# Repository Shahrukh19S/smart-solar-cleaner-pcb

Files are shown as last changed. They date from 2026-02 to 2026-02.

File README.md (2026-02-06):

# Automatic Solar Panel Cleaner — PCB & Firmware

A smart PCB for an **automatic solar panel cleaning system**, designed in Altium Designer. The board has been **manufactured, assembled, and tested** in the field.

## Overview

The system cleans solar panels using a brush and water pump, with motion provided by four motors (forward/back, horizontal, brush). It uses three ultrasonic (sonar) sensors for positioning, a rain sensor, WiFi (ESP-01) and Blynk for control, a 16×2 LCD, RTC, and an Arduino Mega as the main controller. Power input is 7–12 V DC; two relays drive the water pump and brush motor.

## 📹 Demo

### SMART SOLAR CLEANER PCB PINOUT:

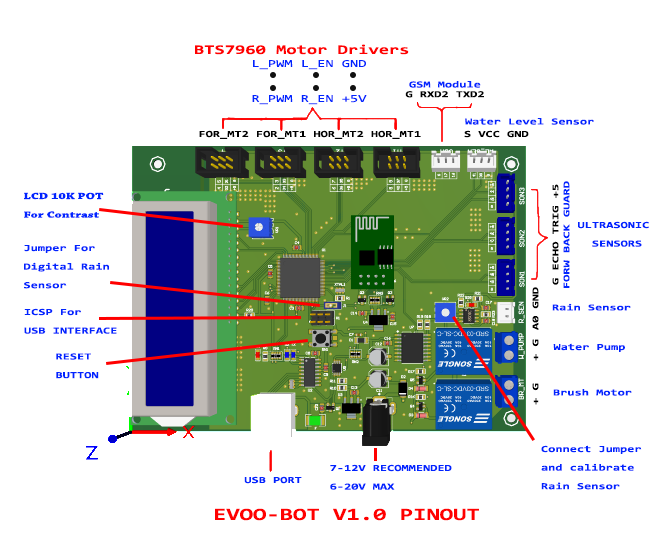
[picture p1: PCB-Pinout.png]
3D View of PCB Board on Altium Designer


## Features

| Category | Details |
|---|---|
| **Controller** | Arduino Mega (ATmega2560) |
| **Connectivity** | ESP-01 (ESP8266) — Blynk app control |
| **Display** | 16×2 LCD |
| **Sensors** | 3× ultrasonic (sonar), rain sensor |
| **Actuators** | 4× motors (2 F/B, 2 horizontal, 1 brush), water pump |
| **Power** | 7–12 V DC input; 2 relays (pump, brush) |
| **Other** | DS3231 RTC, CH340 USB-serial |

## Repository Structure

```
├── README.md                 # This file
├── .gitignore
├── docs/                     # Documentation, schematics, pinout, setup notes
├── hardware/                 # Altium Designer PCB project
│   └── Auto-Solar-Cleaner/   # Source (SchDoc, PcbDoc, PrjPcb) + Gerbers, BOM, DRC
├── firmware/                 # Arduino sketches for this PCB
│   └── Evoo_Bot_V1.0/        # Main firmware (Blynk, RTC, cleaning logic)
├── libraries/                # Arduino/ESP libraries and ESP-01 firmware
└── resources/                # Manuals, reference images
```

## Hardware (PCB)

- **Design tool:** Altium Designer  
- **Location:** `hardware/Auto-Solar-Cleaner/`
- **Source files:** `*.SchDoc`, `*.PcbDoc`, `*.PrjPcb`
- **Manufacturing outputs:** Gerbers, drill files, and assembly data in `Project Outputs for Auto-Solar-Cleaner/`
- **BOM:** `Parts(BOM).xlsx` in the same outputs folder
- **Design rule check:** `Design Rule Check - SOLAR_CLEANER_PCB.html` / `.drc`

Schematic sheets include: ATmega2560, CH340, ESP-01, DS3231, and sensors.

## Firmware

- **Main sketch:** `firmware/Evoo_Bot_V1.0/` — Blynk + RTC + cleaning sequences (dry/wet), sonar-based positioning, rain and water-level checks.
- **Target:** Arduino Mega; serial to ESP-01 for Blynk.
- **Dependencies:** See `firmware/Evoo_Bot_V1.0/README.md` and `libraries/` (Blynk, ESP8266, DS3231, Robojax BTS7960).

Before building, set your Blynk auth token and WiFi credentials. Use `firmware/Evoo_Bot_V1.0/Config.example.h` as a template (copy to `Config.h` and do not commit `Config.h`).

## Libraries

In `libraries/`:

- **Blynk** — `blynk-library-master.zip`, `BlynkESP8266-master.zip`
- **DS3231** — `ds3231FS/` (RTC)
- **Robojax BTS7960** — `Robojax-BTS7960-Motor-driver(Modified)/` (motor driver)
- **ESP-01 AT firmware** — `ESP-At_firmware_1.54/` (Blynk-compatible AT firmware; see `docs/setup-notes.md`)

Install the Arduino libraries and flash the ESP-01 with the provided AT firmware as per the setup notes.

## Documentation

- **Setup and flashing:** `docs/setup-notes.md` (ESP-01 firmware, bootloader, Blynk)
- **Schematics / reference:** `docs/schematics/`, `docs/pinout/`
- **Project overview:** `docs/project-overview.md`

## Bill of Materials (BOM)

- **Location:** `hardware/Auto-Solar-Cleaner/Project Outputs for Auto-Solar-Cleaner/Parts(BOM).xlsx`
- Pick-and-place (centroid) file: `Pick n Place (Centroid).csv` in the same folder.

## Manufacturing & Testing

This PCB has been **manufactured, assembled (hand-soldered), and tested** with the firmware in this repository. Behavior has been verified in real use.

## License

MIT License — see [LICENSE](LICENSE).

## Quick Start

1. Clone the repo and open `hardware/Auto-Solar-Cleaner/Auto-Solar-Cleaner.PrjPcb` in Altium for design review or manufacturing.
2. Install Arduino libraries from `libraries/` and configure Blynk/WiFi (see firmware README and `docs/setup-notes.md`).
3. Flash ESP-01 with `libraries/ESP-At_firmware_1.54/` AT firmware, then build and upload `firmware/Evoo_Bot_V1.0/` to the Arduino Mega.

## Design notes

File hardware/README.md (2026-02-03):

# Hardware — Auto-Solar-Cleaner PCB

Altium Designer project for the **Automatic Solar Panel Cleaner** PCB.

## Contents

- **Source**
  - `Auto-Solar-Cleaner.PrjPcb` — project file (open this in Altium)
  - `*.SchDoc` — schematic sheets (ATmega2560, CH340, ESP-01, DS3231, Sensors)
  - `SOLAR_CLEANER_PCB.PcbDoc` — PCB layout

- **Manufacturing outputs** (`Project Outputs for Auto-Solar-Cleaner/`)
  - **Gerbers** — `.GTL`, `.GBL`, `.GTS`, `.GBS`, `.GTO`, `.GBO`, `.GPT`, `.GPB`, `.GKO`, `.GM*`
  - **Drill** — `.TXT` (round/rect/slot holes), `.LDP`, `.DRR`
  - **Assembly** — `Pick n Place (Centroid).csv`
  - **BOM** — `Parts(BOM).xlsx`
  - **DRC** — `Design Rule Check - SOLAR_CLEANER_PCB.html` / `.drc`
  - **Archive** — `Final PCB (V1).zip`

## Main parts (summary)

- Arduino Mega (ATmega2560), CH340 USB-serial
- ESP-01 (ESP8266), DS3231 RTC
- 16×2 LCD, 3× ultrasonic sensors, rain sensor
- 4× motors (BTS7960 drivers), water pump, brush motor
- 2× relays (pump, brush); 7–12 V DC input

## Viewing without Altium

- Open the **Design Rule Check** report (`.html`) for a net/spec overview.
- View **schematic images** in the repo under `docs/schematics/` (e.g. rain sensor).
- **Pinout:** `docs/pinout/PCB-Pinout.png`

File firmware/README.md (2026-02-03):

# Firmware — Automatic Solar Panel Cleaner

Arduino sketches for the **Auto-Solar-Cleaner** PCB (Arduino Mega + ESP-01, Blynk, RTC, motors, sensors).

## Main sketch: Evoo_Bot_V1.0

- **Path:** `Evoo_Bot_V1.0/`
- **Board:** Arduino Mega (ATmega2560)
- **Features:** Blynk control, RTC scheduling, dry/wet cleaning, 3× sonar positioning, rain and water-level checks, LCD, relay control for pump and brush.

### Dependencies

Install in your Arduino `libraries` folder (or Arduino IDE **Sketch → Include Library → Add .ZIP Library**):

- **Blynk** — from repo `libraries/blynk-library-master.zip` and `libraries/BlynkESP8266-master.zip` (or unzip and copy)
- **ESP8266 for Arduino** — [ESP8266 core](https://github.com/esp8266/Arduino) (for `ESP8266_Lib.h` / Blynk ESP8266)
- **DS3231 RTC** — use repo `libraries/ds3231FS/`
- **Robojax BTS7960** — use repo `libraries/Robojax-BTS7960-Motor-driver(Modified)/`

### Configuration (do not commit secrets)

Set your Blynk auth token and WiFi credentials before compiling:

1. **Option A:** Create a file `Config.h` in the sketch folder (add `#include "Config.h"` in the main `.ino`) with:
   - `char auth[] = "YOUR_BLYNK_AUTH";`
   - `char ssid[] = "YOUR_WIFI_SSID";`
   - `char pass[] = "YOUR_WIFI_PASSWORD";`
2. **Option B:** Edit the placeholders in `Evoo_Bot_V1.0.ino` and **do not commit** those changes (or use a separate private branch).

Add `Config.h` to `.gitignore` (already listed in the repo root `.gitignore`).

### Pin definitions

See `Globals.h`: rain sensor, water level, pump/brush (A1/A2), sonar trigger/echo, motor PWM and enable pins, LCD pins. Matches the PCB design in `hardware/`.

### ESP-01

- Use **Serial1** on the Mega to talk to the ESP-01.
- Flash the ESP-01 with Blynk-compatible AT firmware (e.g. V1.5.4 in `libraries/ESP-At_firmware_1.54/`). See `docs/setup-notes.md`.
- Set ESP-01 baud rate to **9600** (AT command) to match the sketch.

## Other sketches

- **Blynk_RTC** — Blynk + RTC utilities (used or referenced by main logic).
- **SolarCleaner(Original)-Copy** — earlier version of the cleaner logic.
- **NodeMCU** — standalone NodeMCU sketch (optional).

## Building

1. Open `Evoo_Bot_V1.0/Evoo_Bot_V1.0.ino` in the Arduino IDE.
2. Select board **Arduino Mega or Mega 2560** and the correct port.
3. Install all libraries above; add your Blynk/WiFi config.
4. Compile and upload to the Mega.

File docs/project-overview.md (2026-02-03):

# Project Overview — Automatic Solar Panel Cleaner

## System Summary

This project implements a **smart PCB** for an automatic solar panel cleaning robot. The hardware and firmware in this repository have been **manufactured, assembled, and tested** successfully.

## Main Components (from project spec)

1. **Ultrasonic (waterproof) sensors** — 3× (positioning / boundaries)
2. **Rain sensor** — for weather-aware operation
3. **WiFi** — ESP-01 (ESP8266) for Blynk app control
4. **Solar charge controller** — system power management
5. **Automatic battery charging and discharging**
6. **Motors** — 5 in total: 2 forward/back, 2 horizontal, 1 brush
7. **Blynk** — mobile app for scheduling and control
8. **Real-time clock (RTC)** — DS3231 for alarms and scheduling
9. **Target deployment** — e.g. 22 m × 6 m solar panel array; one dedicated panel for the cleaner
10. **SIM module** — (optional) for SMS alerts
11. **Arduino Mega** — main controller
12. **LCD** — 16×2 display
13. **Water level sensor** — tank level for wet cleaning
14. **Water pump** — wet cleaning; controlled via relay

## PCB Highlights

- **Input:** 7–12 V DC  
- **Relays:** 2 — one for water pump, one for brush motor  
- **Design:** Altium Designer (see `hardware/`)

## Documentation Map

- **Setup (ESP-01, bootloader, Blynk):** [setup-notes.md](setup-notes.md)
- **Schematic images:** `docs/schematics/`
- **Pinout:** `docs/pinout/PCB-Pinout.png`
- **Blynk-supported ESP firmwares:** `docs/Blynk_Supported_Firmwares.JPG`

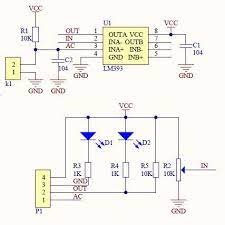
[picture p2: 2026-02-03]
docs/schematics/Rain Sensor Schematic.jpg

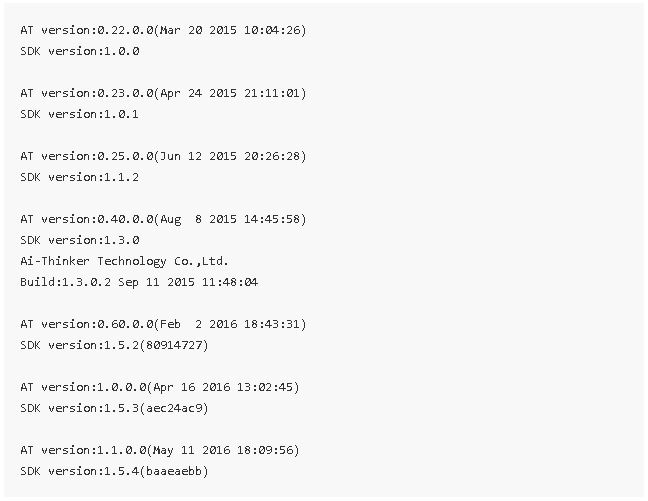
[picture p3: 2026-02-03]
docs/Blynk_Supported_Firmwares.JPG

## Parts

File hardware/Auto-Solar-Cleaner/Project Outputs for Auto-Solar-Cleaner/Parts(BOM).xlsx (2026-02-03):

Designator | Quantity | Mfg Part # | Comment/ value | Footprint | Type | LibRef
XTAL1 | 1 | 16MHz Resonator | 16MHz with 22pF internal capacitors |  | SMD | Crystal Oscillator
TX | 1 | SMT LED | TX LED (Blue) | SMD-0805 | SMD | LED 5V
RX | 1 | SMT LED | RX LED (Blue) | SMD-0805 | SMD | LED 5V
D2 | 1 | 1N4007 | M7 | D0214AC(SMA-2) | SMD | Diode
D1 | 1 | CD1206-SO1575 | Switching Diode by Bourns(Manufacturer) | D1206-RD | SMD | Diode
U7 | 1 | DS3231SN# | Real Time Clock IC | DS3231(footprint) | SMD | DS3231SN#
C11, C12 | 2 | Electrolytic Capacitor | 47uF/ 25V | Elec-Cap-SMD | SMD | Cap Pol2
R_SEN | 1 | JST Connector Male,Pitch 2.54mm, 2-Pin | Rain Sensor Connector | HDR1X2 | Thru-hole | Header 2
J1 | 1 | Male Header Jumper, Pitch 2.54mm 2-Pin | Jumper | HDR1X2 | Thru-hole | Header 2
GSM | 1 | JST Connector Male, Pitch 2.54mm, 3-Pin | GSM Connector | HDR1X3 | Thru-hole | Header 3
WL_SEN | 1 | JST Connector Male, 3-Pin | Water Level Sensor Connector | HDR1X3 | Thru-hole | Header 3
SON1 | 1 | JST Connector Male, 4-Pin | Ultrasonic Sensor Connector | HDR1X4 | Thru-hole | Header 4
SON2 | 1 | JST Connector Male, 4-Pin | Ultrasonic Sensor Connector | HDR1X4 | Thru-hole | Header 4
SON3 | 1 | JST Connector Male, 4-Pin | Ultrasonic Sensor Connector | HDR1X4 | Thru-hole | Header 4
H10 | 1 | Female Header, Pitch 2.54mm, 16-Pin, Vertical | Header 16H For 16x2 LCD Module | HDR1X16H | Thru-hole | Header 16H
H1 | 1 | Male Header, 6-Pin- Dual row(2x3) ICSP | ICSP | HDR2X3 | Thru-hole | Header 3X2
MT4 | 1 | Male Shrouded Box Header (IDC), Pitch 2.54mm, 6-Pin- Dual row(2x3) | Motor-MT4 | HDR2X3 | Thru-hole | Header 3X2
MT3 | 1 | Male Shrouded Box Header (IDC), Pitch 2.54mm, 6-Pin- Dual row(2x3) | Motor-MT3 | HDR2X3 | Thru-hole | Header 3X2
MT2 | 1 | Male Shrouded Box Header (IDC), Pitch 2.54mm, 6-Pin- Dual row(2x3) | Motor-MT2 | HDR2X3 | Thru-hole | Header 3X2
MT1 | 1 | Male Shrouded Box Header (IDC), Pitch 2.54mm, 6-Pin- Dual row(2x3) | Motor-MT1 | HDR2X3 | Thru-hole | Header 3X2
H6 | 1 | Female Header,Pitch 2.54mm, 8-Pin-Dual row(2x4) | Header 4X2 For ESP-01 Wifi Module | HDR2X4 | Thru-hole | Header 4X2
BR_MT | 1 | 2-pin Screw Terminal Block (Normal) | For Brush Motor | Header_I2 | Thru-hole | Header_I2
W_PUMP | 1 | 2-pin Screw Terminal Block (Normal) | For Water Pump | Header_I2 | Thru-hole | Header_I2
D3, D4 | 2 | 1N4148 | Switching Diode | LL4148-L3.7 SMD(LCSC) | SMD | Diode 1N4148
F | 1 | MF-MSMF050-2 | Fuse by Bourns | MF-MSMF050-2 (LCSC) | SMD | Fuse 1
X1 | 1 | DC- Barrel Power Jack /Connector (Female) | PJ-002A | PJ-002A | Thru-hole | PJ-002A
RN1 | 1 | Resistor Network | 1K | RA0603-8 | SMD | RES_NETWORK
RN2, RN3 | 2 | Resistor Network | 10K | RA0603-8 | SMD | RES_NETWORK
ON | 1 | SMT LED | Red LED | SMD-0805 | SMD | LED 5V
SIG | 1 | SMT LED | Red LED (For Rain Sensor) | SMD-0805 | SMD | LED 5V
C7 | 1 | Ceramic Capacitor | 22pF | SMD-0603 | SMD | GC321AD72E103KX01D
C3, C4, C5, C6, C8, C9, C10, C13, C16, C17, C18 | 11 | Ceramic Capacitor | 100nF | SMD-0805 | SMD | GC321AD72E103KX01D
C14, C15 | 2 | Ceramic Capacitor | 10uF | SMD-0805 | SMD | GC321AD72E103KX01D
R1 | 1 | SMD Resistor | 1M | SMD-0805 | SMD | ERJ-6BQF1R1V
R9, R21 | 2 | SMD Resistor | 1K | SMD-0805 | SMD | ERJ-6BQF1R1V, ERJ-6BQF1R0V
R10, R11, R22, R23 | 4 | SMD Resistor | 10K | SMD-0805 | SMD | ERJ-6BQF1R1V, ERJ-6BQF1R0V
R16, R17 | 2 | SMD Resistor | 1K | SMD-0805 | SMD | Res1
R18, R19 | 2 | SMD Resistor | 4.7K | SMD-0805 | SMD | ERJ-6BQF1R0V
R20 | 1 | SMD Resistor | 220 ohm | SMD-0805 | SMD | ERJ-6BQF1R0V
Q2, Q3 | 2 | BSS138 | N-Channel MOSFET | SMT_TRIODE_NPN | SMD | BSS138
Q4, Q5 | 2 | S8050 NPN | S8050 NPN Bipolar Junction Transistor (BJT) SMD CODE=J3Y | SOT-23-3 | SMD | S8050
U8 | 1 | LM393EDR2G | Comparator | SOIC-8 | SMD | LM393
U2 | 1 | CH340C | USB to Serial Chip | SOIC-16 150MIL(LCSC) | SMD | CH340C
Q1 | 1 | FDN340P | P-Channel MOSFET SMD CODE=A1SHB | SOT-23-3 | SMD | FDN340P
U3 | 1 | AMS1117-5.0 | AMS1117-5.0, Voltage Regulator | SOT-223 | SMD | AMS1117
U4 | 1 | AMS1117-3.3 | AMS1117-3.3, Voltage Regulator | SOT-223 | SMD | AMS1117
SW1 | 1 | 5 Pin Reset Button of Arduino UNO | 5 Pin Switch | SPDT-5Pin | SMD | SPDT-SWITCH
K1, K2 | 2 | SRD-05VDC-SL-C | 5V Trigger Relay Module For Arduino And Raspberry Pi | SRD-05VDC-SL-C | Thru-hole | SRD-05VDC-SL-C
U1 | 1 | ATMEGA2560-16AU | Arduino Mega Controller IC | TQFP-100(LCSC) | SMD | ATMEGA2560-16AU (LCSC)
X2 | 1 | USB-Type B Female | USB type B For Printer | USB-TypeB Female (LCSC) | Thru-hole | USB-Type B
VR1, VR2 | 2 | Potentiometer | 10K potentiometer | VR7(LCSC) | Thru-hole | RPot
U5 | 1 | LMV358IDGKR | Op-Amp | VSSOP-8 | SMD | LM358

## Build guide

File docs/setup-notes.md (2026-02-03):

# Setup Notes — ESP-01, Bootloader, Blynk

## ESP-01 AT firmware and Blynk

- **Important:** Newer AT firmware versions (e.g. latest from Espressif) may **not** work with Blynk.
- **Tested working:** Firmware **V1.5.4** (included in this repo under `libraries/ESP-At_firmware_1.54/`).
- **Reference:** List of Blynk-supported ESP firmwares is in the project image `Blynk_Supported_Firmwares.JPG` and at:  
  [Blynk: ESP8266 with AT firmware](http://help.blynk.cc/en/articles/605485-esp8266-with-at-firmware).
- **Firmware source (external):**  
  [Edragon esp_firmware — AI-THINKER At_firmware_bin1.54](https://github.com/Edragon/esp_firmware/tree/master/Firmware/AT-other/AI-THINKER/At_firmware_bin1.54).
- **Flashing guide (YouTube):** Nathan Church — [How to flash ESP-01 firmware](https://www.youtube.com/watch?v=YLKEZtLhfZo).
- **Baud rate:** After flashing, set ESP-01 baud rate to **9600** (e.g. via AT commands); the Mega sketch uses 9600 for `Serial1`.

## Arduino Mega bootloader

- **Guide:** Nick Gammon — [Arduino Mega Bootloader and upload](http://www.gammon.com.au/bootloader).
- **Sketches / reference:** [nickgammon/arduino_sketches](https://github.com/nickgammon/arduino_sketches).

## Libraries used in this project

- **Robojax BTS7960** — slightly modified in this repo; see `libraries/Robojax-BTS7960-Motor-driver(Modified)/`.
- **Blynk** — use the Blynk libraries included (or linked) in `libraries/` (e.g. `blynk-library-master.zip`, `BlynkESP8266-master.zip`).

## ESP-01 firmware files (V1.5.4)

Located in `libraries/ESP-At_firmware_1.54/`:

- `AiThinker_ESP8266_DIO_8M_8M_20160615_V1.5.4.bin` — 8 Mbit flash
- `AiThinker_ESP8266_DIO_32M_32M_20160615_V1.5.4.bin` — 32 Mbit flash

Flash at address **0x00000**. Use a tool such as ESP_DOWNLOAD_TOOL_V2.4; if unsure, use the “DoNotChgBin” default configuration.

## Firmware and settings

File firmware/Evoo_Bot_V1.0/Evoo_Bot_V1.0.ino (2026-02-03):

/*
	Name:       Evoo_Bot_V1.0.ino
	Created:	4/24/2021 8:23:33 PM
	Author:     Abdullah Ansari
*/

#define BLYNK_PRINT Serial

#include "Globals.h"
#include <ESP8266_Lib.h>
#include <BlynkSimpleShieldEsp8266.h>
#include <LiquidCrystal.h>
#include "support_rtc.h"
#include "support_func.h"
#include "cleaner_driver.h"

// You should get Auth Token in the Blynk App.
// Go to the Project Settings (nut icon).
// Option: use Config.h (copy from Config.example.h) and #include "Config.h" instead of defining here.
char auth[] = "YOUR_BLYNK_AUTH_TOKEN";

// Your WiFi credentials (for ESP-01). Set password to "" for open networks.
char ssid[] = "YOUR_WIFI_SSID";
char pass[] = "YOUR_WIFI_PASSWORD";

// Hardware Serial on Mega, Leonardo, Micro...
#define EspSerial Serial1

// Your ESP8266 baud rate:
#define ESP8266_BAUD 9600	//Don't forget to permanently change the default baud rate of ESP fromm 115200 to 9600 using AT							  //command

//LCD Pins setup
LiquidCrystal lcd(LCD_RS, LCD_EN, LCD_D4, LCD_D5, LCD_D6, LCD_D7);

ESP8266 wifi(&EspSerial);

uint8_t curr_HOUR = 00;
uint8_t curr_MIN = 00;
uint8_t curr_SEC = 00;


uint8_t ALARM_HOUR = 00;
uint8_t ALARM_MIN = 00;
uint8_t ALARM_SEC = 00;

/************************ The reference of this two variables is given to saveAlarmTime() function in order to save the Alarm Times in support_rtc.cpp ********************************
  *- We must keep this variable references valid until the Alarm is not set on RTC, therefore, they're defined here(not local variables)
*/
char on_time_str[20];
char off_time_str[20];

boolean isFreeA1 = true;
boolean isFreeA2 = true;

uint8_t total_segments;
uint8_t current_segment;
boolean cleaner_allow_back = true;



CleanerDriver cleaner;

BLYNK_WRITE(V1) // Start Button Widget writes to Virtual Pin V1
{
	if (param.asInt() == 1) {     // if Button sends 1
		Serial.println("Cleaner is turned ON");
		SendSms(PHONE_NO, WARN_CLEANER_RUN);
		DryCleaning();
		WetCleaning();

	}
}

/* This method is called automatically when the user selects the start time on the time input widget
	*- Remember- even though you change nothing(start, timezone, days) and press OK button in the time input widget, this method will be called with the current start, timezone and days.
*/

BLYNK_WRITE(V2) {
	TimeInputParam t(param);

	// Process start time

	if (t.hasStartTime())
	{
		//t.getStartHour = Alarm Time in Hours
		// ALARM_HOUR, ALARM_MINUTE is the Elaps Time after subtraction, like 00:02 (2 minutes Alarm)
		ALARM_HOUR = (t.getStartHour() > curr_HOUR) ? t.getStartHour() - curr_HOUR : curr_HOUR - t.getStartHour();
		//t.getStartMinute =  Alarm Time in Minutes.
		ALARM_MIN = (t.getStartMinute() > curr_MIN) ? t.getStartMinute() - curr_MIN : curr_MIN - t.getStartMinute();
		ALARM_SEC = (t.getStartSecond() > curr_SEC) ? t.getStartSecond() - curr_SEC : curr_SEC - t.getStartSecond();

		/******************************************************************************************************
		 if alarm_time_str[20] were used it will create two references, one here and the second one in t.hasStopTime() even though the name is same.
		 and since we couldn't keep the references (1st reference would be destroyed when the second alarm_time_str is created since the name is same )
		 we would've garbage values in support_rtc.cpp. therefore, two variables (on_time_str and off_time_str were created globally)
		 *****************************************************************************************************/
		 //char alarm_time_str[20];

		sprintf(on_time_str, "%02d:%02d:%02d", ALARM_HOUR, ALARM_MIN, ALARM_SEC);

		Serial.print("Start Log is =");
		Serial.println(on_time_str);

		//save the ON Time in support_rtc.cpp
		RTC::saveAlarmTime(1, on_time_str);

		Serial.println(String("Start: ") +
			t.getStartHour() + ":" +
			t.getStartMinute() + ":" +
			t.getStartSecond());
	}
	else if (t.isStartSunrise())
	{
		Serial.println("Start at sunrise");
	}
	else if (t.isStartSunset())
	{
		Serial.println("Start at sunset");
	}
	else
	{
		// Do nothing
	}

	// Process timezone
	// Timezone is already added to start/stop time

	Serial.println(String("Time zone: ") + t.getTZ());

	// Get timezone offset (in seconds)
	Serial.println(String("Time zone offset: ") + t.getTZ_Offset());

	// Process weekdays (1=Mon, 2=Tue, 3=Wed, ...)

	//for (int i = 1; i <= 7; i++) {
	//	if (t.isWeekdaySelected(i)) {
	//		Serial.println(String("Day ") + i + " is selected");
	//	}
	//}

	Serial.println();
}


/**************************************************************************************************
This method is called when the user selects the Stop Time for the cleaner on the Time input Widget.
	1: This method can set the alarm time on RTC but when its triggered it doesn't do anything. Since, for stopping the		 cleaner we must stop it under the cleaner Guard.
***************************************************************************************************/
/*
BLYNK_WRITE(V3) {
	TimeInputParam t(param);

	// Process stop time

	if (t.hasStopTime())
	{
		//t.getStopHour = Alarm Time in Hours
		// ALARM_HOUR, ALARM_MINUTE is the Elaps Time after subtraction, like 00:02 (2 minutes Alarm)
		ALARM_HOUR = (t.getStopHour() > curr_HOUR) ? t.getStopHour() - curr_HOUR : curr_HOUR - t.getStopHour();
		//t.getStartMinute =  Alarm Time in Minutes.
		ALARM_MIN = (t.getStopMinute() > curr_MIN) ? t.getStopMinute() - curr_MIN : curr_MIN - t.getStopMinute();
		ALARM_SEC = (t.getStopSecond() > curr_SEC) ? t.getStopSecond() - curr_SEC : curr_SEC - t.getStopSecond();

		sprintf(off_time_str, "%02d:%02d:%02d", ALARM_HOUR, ALARM_MIN, ALARM_SEC);

		Serial.print("Stop Log is =");
		Serial.println(off_time_str);

		//save the OFF Time in support_rtc.cpp
		RTC::saveAlarmTime(2, off_time_str);

		Serial.println(String("Stop: ") +
			t.getStopHour() + ":" +
			t.getStopMinute() + ":" +
			t.getStopSecond());
	}
	else if (t.isStopSunrise())
	{
		Serial.println("Start at sunrise");
	}
	else if (t.isStopSunset())
	{
		Serial.println("Start at sunset");
	}
	else
	{
		// Do nothing
	}

	// Process timezone
	// Timezone is already added to start/stop time

	Serial.println(String("Time zone: ") + t.getTZ());

	// Get timezone offset (in seconds)
	Serial.println(String("Time zone offset: ") + t.getTZ_Offset());

	// Process weekdays (1. Mon, 2. Tue, 3. Wed, ...)

	//for (int i = 1; i <= 7; i++) {
	//	if (t.isWeekdaySelected(i)) {
	//		Serial.println(String("Day ") + i + " is selected");
	//	}
	//}

	Serial.println();
}
*/


/************Gets the current time to calculate exact Alarm time.
	*- e.g. if 12:05 is the Alarm Time and current time is 12:00, then exact Alarm time is 00:05 (5 minutes)
	*- this 00:05 alarm time is with respect to 00:00 Time which is the default time set on RTC when the hardware started
	*- So, whatever the current time is on RTC, we just have to add 00:05 (5 minutes) to the current time on RTC.

	NOTE: YOU MUST SET THE CURRENT TIME FIRST BEFORE SETTING THE ALARM TIME FOR START/STOP CLEANER.
*/
BLYNK_WRITE(V3) {
	TimeInputParam t(param);

	// Process start time

	if (t.hasStartTime())
	{
		curr_HOUR = t.getStartHour();
		curr_MIN = t.getStartMinute();
		curr_SEC = t.getStartSecond();

		Serial.println(String("Current Time: ") +
			curr_HOUR + ":" +
			curr_MIN + ":" +
			curr_SEC);
	}
	else if (t.isStartSunrise())
	{
		Serial.println("Start at sunrise");
	}
	else if (t.isStartSunset())
	{
		Serial.println("Start at sunset");
	}
	else
	{
		// Do nothing
	}

	// Process timezone
	// Timezone is already added to start/stop time

	Serial.println(String("Time zone: ") + t.getTZ());

	// Get timezone offset (in seconds)
	Serial.println(String("Time zone offset: ") + t.getTZ_Offset());

	// Process weekdays (1. Mon, 2. Tue, 3. Wed, ...)

	//for (int i = 1; i <= 7; i++) {
	//	if (t.isWeekdaySelected(i)) {
	//		Serial.println(String("Day ") + i + " is selected");
	//	}
	//}

	Serial.println();
}


/* When the hardware is connected to Blynk cloud, it will call this method automatically.
	*- This method will update the start/stop time, timezone and days on the time input widget.
	*- This method can be used to set the default time on the time input widget when the hardware starts but it requires to
		set the same time as alarm on the RTC, so it will turn the cleaner ON when the alarm goes off.
*/
/*BLYNK_CONNECTED() {
	//seconds from the start of a day. 0 - min, 86399 - max
	int startAt = 5 * 60; //00:05

	//seconds from the start of a day. 0 - min, 86399 - max
	int stopAt = (60 + 5) * 60; //01:05

	//timezone
	//full list of supported timezones could be found here
	//https://www.mkyong.com/java/java-display-list-of-timezone-with-gmt/
	char tz[] = "Asia/Karachi";

	Blynk.virtualWrite(V1, startAt, stopAt, tz);

	//you may also pass day
	//char days[] = "1"; //Monday
	//Blynk.virtualWrite(V1, startAt, stopAt, tz, days);

	//or days
	//char days[] = "1,2,3"; //Monday, Tuesday, Wednesday
	//Blynk.virtualWrite(V1, startAt, stopAt, tz, days);
}

*/


void setup()
{
	Serial.begin(9600);
	delay(10);

	// Set ESP8266 baud rate
	EspSerial.begin(ESP8266_BAUD);
	delay(10);

	//Set Serial2 for GSM and configure GSM in Text_mode
	GSMInit();

	//Initiallize LCD 
	lcd.begin(16, 2);		//col = 16, row = 2(starts from 0) 
	lcd.print("** Smart Solar *");
	lcd.setCursor(0, 1);	//sets cursor to col=0, row=1 
	lcd.print("  Panel Cleaner ");
	for (int p = 0; p <= 5; p++) {
		BlinkLCDText();
	}

	lcd.clear();		//clear Text on LCD and sets cursor to col=0, row=0
	lcd.blink();		//shows blinking cursor 

	//connects to Wifi and Blynk Server
	Blynk.begin(auth, wifi, ssid, pass);

	//Initiallize RTC and sets 00:00:00 time on RTC
	RTC::RTCInit();

	//Initiallize Sensor Pins
	Init();

	// Initiallize all motors of Cleaner.
	cleaner.Init();

}

void loop()
{
	Blynk.run();
	//send SMS to the user when there isn't enough water in the tank for the Wet Cleaning.
	if (readWaterLevel() == 0) {
		lcd.setCursor(0, 0);
		lcd.print("Water Tank empty");	//It is Raining
		SendSms(PHONE_NO, WARN_WATER_LEVEL);
	}

	//send SMS to the user when it's raining.
	if (readRainSensor() == 0) {
		lcd.setCursor(0, 0);
		lcd.print("It's Raining !");
		SendSms(PHONE_NO, WARN_RAINING);
	}

	if (RTC::isAlarmTime()) {
		if (isFreeA1) {
			Serial.println("Alarm A1 is about to set");
			RTC::setAlarmA1();
			isFreeA1 = false;
		}
		/***********************  Currently Stop Time for Cleaner is not implemented********************************/
		/***********************  Would be better to implement it with 4 ultrasonic Sensors*************************/
		/*
		else if (isFreeA2) {
			Serial.println("Alarm A2 is about to set");
			RTC::setAlarmA2();
			isFreeA2 = false;
		}*/
	}

	if (RTC::isTrigA1()) {
		Serial.println("\nCleaner turned ON after A1 Alarm Trigger");
		isFreeA1 = true;
		RTC::resetFlagsA1();
		SendSms(PHONE_NO, WARN_CLEANER_RUN_ALARM_TRIG);
		DryCleaning();
		WetCleaning();
	}
	/*****************************no Stop Time for the Cleaner is implemented*******************************/
	/*
	if (RTC::isTrigA2()) {
		Serial.println("\nCleaner turned OFF after A2 Alarm Trigger");
		isFreeA2 = true;
		RTC::resetFlagsA2();
	}*/
}


void updateSerial()
{
	delay(500);
	while (Serial.available())
	{
		Serial2.write(Serial.read());//Forward what Serial received to Software Serial Port
	}
	while (Serial2.available())
	{
		Serial.write(Serial2.read());//Forward what Software Serial received to Serial Port
	}
}

void GSMInit() {
	//Begin serial communication with Arduino and SIM900
	Serial2.begin(9600);

	Serial.println("Initializing...");
	delay(1000);

	Serial2.println("AT"); //Handshaking with SIM900
	updateSerial();

	Serial2.println("AT+CMGF=1"); // Configuring TEXT mode, The text message entered followed by a �Ctrl+z� character is							// treated as SMS.
	updateSerial();

}
/************************* SEND SMS to the Phone Number specified******************************
	*- ph_no format: "\"+ZZxxxxxxxxxx\"" where ZZ= country code, xxxxxxxxxx = phone number

	*- AT command: AT+CMGS=+ZZxxxxxxxxxx command for specifying phone number for sms
*/
void SendSms(const char* ph_no, const char* text_msg) {
	char at_ph_cmd[30]; //AT command buffer for specifying the phone number
	// AT+CMGS command used with ph_no given to this function
	snprintf(at_ph_cmd, sizeof(at_ph_cmd), "AT+CMGS=%s", ph_no);
	//write AT command buffer to GSM over Serial.
	//uncomment this line if ph_no is used.
	Serial2.println(at_ph_cmd);

	//phone number and AT command is specified in single line
	//uncomment this line if phone_no is specified here.
	//Serial2.println("AT+CMGS=\"+ZZxxxxxxxxxx\"");	//change ZZ with country code and xxxxxxxxxxx with phone number to sms
	updateSerial();

	//uncomment this line if you want to send this sms text
	//Serial2.print("Evoo-Bot V1.0 by Helios Energy co. Jordan"); //text content

	//uncomment this line if you want to send text_msg given to this function
	Serial2.print(text_msg);
	updateSerial();

	Serial2.write(26); //CTRL+Z is 26 decimal in ASCII
}

/*********************************************************************************************************************
Moves Cleaner Forward and Backward using Segment to Segment movement from right to left.
**********************************************************************************************************************/
void DryCleaning(void) {
	lcd.setCursor(0, 0);
	lcd.print("Cleaning Solar !");
	lcd.setCursor(0, 1);
	lcd.print("Dry Cleaning !!");
	delay(500);
	while (1) {
		lcd.clear();
		lcd.print("Cleaner Forward !");
		int f_Distance = GetForDistance();
		while (!(f_Distance > 0 && f_Distance <= 4)) {
			cleaner.forward(FOR_SPEED_MT);
			delay(20);
			f_Distance = GetForDistance();
			if (f_Distance > 0 && f_Distance <= 4) {		// cleaner reached extreme forward edge.
				cleaner.for_stop(); //forward/backward motor stops
				delay(20);
				current_segment++;
				lcd.setCursor(0, 1);
				lcd.print("Edge Detected !!");
				Serial.print("Current Segment = ");
				Serial.println(current_segment);
				//run cleaner horizontally towards left side with SEGMENT_DELAY (change SEGMENT_DELAY by trial and error)
				cleaner.segment_left(HOR_SPEED_MT);
				//check if the left edge of Solar Panel is detected
				int h_Distance = GetGuardDistance();
				if (h_Distance >= 12 && h_Distance <= 27) {
					Serial.println("Solar Panel Left Edge Detected !!");
					total_segments = current_segment;
					Serial.print("Total Segments = ");
					Serial.println(total_segments);
					cleaner_allow_back = false;
				}
				break;
			}
		}
		lcd.clear();
		lcd.print("Cleaner backward");
		int b_Distance = GetBackDistance();
		while (!(b_Distance >= 6 && b_Distance <= 10) && cleaner_allow_back) {
			cleaner.backward(FOR_SPEED_MT);
			delay(20);
			b_Distance = GetBackDistance();
			if (b_Distance >= 6 && b_Distance <= 10) {
				cleaner.for_stop();
				delay(20);
				lcd.setCursor(0, 1);
				lcd.print("Edge Detected !!");
				break;
			}
		}
		if (total_segments == current_segment) {
			Serial.println("Dry Cleaning Done !!!");
			lcd.clear();
			lcd.print("Dry Cleaning");
			lcd.setCursor(0, 1);
			lcd.print("	  Done !!   ");
			//Turn on Water Pump 
			w_pump_start();
			cleaner_allow_back = true;
			break;
		}
	}
}

/*********************************************************************************************************************
moves cleaner from left to right using Segment to Segment movement(Wet Cleaning).
**********************************************************************************************************************/
void WetCleaning(void) {
	lcd.clear();
	lcd.print("Wet Cleaning");
	lcd.setCursor(0, 1);
	lcd.print("   Started !!");
	delay(100);
	while (current_segment != 0) {
		cleaner.segment_right(HOR_SPEED_MT);
		current_segment--;
		//this is the point where solar panel edge is detected, next segment is cleaner guard
		if (current_segment == current_segment - 1) {
			Serial.println("Right Solar Edge Detected!!");
			cleaner.hor_stop();
			delay(20);
			//Turn OFF Water Pump
			w_pump_stop();

		}
		if (current_segment == 0) {
			cleaner.hor_stop();
			delay(20);
			break;
		}
	}

	if (current_segment == 0) {
		int b_Distance = GetBackDistance();
		while (!(b_Distance >= 6 && b_Distance <= 10)) {
			cleaner.backward(FOR_SPEED_MT);
			delay(20);
			b_Distance = GetBackDistance();
			if (b_Distance >= 6 && b_Distance <= 10) {
				lcd.clear();
				lcd.print("Wet Cleaning");
				lcd.setCursor(0, 1);
				lcd.print("    Done !!   ");
				//Cleaner is now under Cleaner Guard.
				cleaner.stop();		//stop the whole cleaner
				delay(20);
				break;
			}
		}
	}
}


void BlinkLCDText() {
	lcd.noDisplay();
	delay(500);
	lcd.display();
	delay(500);
}

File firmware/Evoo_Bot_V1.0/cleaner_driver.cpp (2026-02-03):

#include "cleaner_driver.h"
#include <RobojaxBTS7960.h>
#include "Globals.h"
#include "Arduino.h"

/************* Self Modified Version of BTS7960 library is used, original is available at Robojax here
http://bit.ly/bts7960-library
*/

/********** Two Motor objects for forward/backward(up/down) Movements*********************/
RobojaxBTS7960 forwardMT1(FOR1_R_EN, FOR1_RPWM, FOR1_L_EN, FOR1_LPWM, debug);
RobojaxBTS7960 forwardMT2(FOR2_R_EN, FOR2_RPWM, FOR2_L_EN, FOR2_LPWM, debug);

/********** Two Motor objects for Horizontal Movements (right/left) *********************/
RobojaxBTS7960 horizontalMT1(HOR1_R_EN, HOR1_RPWM, HOR1_L_EN, HOR1_LPWM, debug);
RobojaxBTS7960 horizontalMT2(HOR2_R_EN, HOR2_RPWM, HOR2_L_EN, HOR2_LPWM, debug);


void CleanerDriver::Init() {
	forwardMT1.begin();
	forwardMT2.begin();
	horizontalMT1.begin();
	horizontalMT2.begin();
	/* sets Brush Motor relay pin as OUTPUT*/
	pinMode(BR_MT, OUTPUT);
	// turn off Brush Motor initially(active LOW)
	digitalWrite(BR_MT, HIGH);

}

/*************runs the cleaner forward along with brush motor********
*- speed: 0-100
*/
void CleanerDriver::forward(int speed) {
	forwardMT1.rotate(speed, CW);
	forwardMT2.rotate(speed, CW);
	// turn on the Brush Motor
	digitalWrite(BR_MT, LOW); // change wires of Brush motor in relay connections, if direction is reversed;
	horizontalMT1.stop();
	horizontalMT2.stop();
}

void CleanerDriver::backward(int speed) {
	forwardMT1.rotate(speed, CCW);
	forwardMT2.rotate(speed, CCW);
	// turn on the Brush Motor
	digitalWrite(BR_MT, LOW); // change wires of Brush motor in relay connections, if direction is reversed;
	horizontalMT1.stop();
	horizontalMT2.stop();
}

/******* runs the cleaner horizontally on the solar panel using Segment to Segment movement
*-SEGMENT_DELAY: calculate this delay to move cleaner horizontally for a moment
*- stops all motors during Segment to Segment movement except horizontal motors
*- cleaner movement from right to left is considered DRY CLEANING
*/
void CleanerDriver::segment_left(int speed) {
	forwardMT1.stop();
	forwardMT2.stop();
	// turn off the Brush Motor
	digitalWrite(BR_MT, HIGH);
	horizontalMT1.rotate(speed, CCW);
	horizontalMT2.rotate(speed, CCW);
	delay(SEGMENT_DELAY); //calculated delay(by trial and error) for the segment to segment movement
	horizontalMT1.stop();
	horizontalMT2.stop();
}

/******* runs the cleaner horizontally on the solar panel using Segment to Segment movement
*-SEGMENT_DELAY: calculate this delay to move cleaner horizontally for a moment
*- cleaner movement from left to right is considered WET CLEANING
*/
void CleanerDriver::segment_right(int speed) {
	forwardMT1.stop();
	forwardMT2.stop();
	// turn off the Brush Motor
	digitalWrite(BR_MT, HIGH);
	horizontalMT1.rotate(speed, CW);
	horizontalMT2.rotate(speed, CW);
	delay(SEGMENT_DELAY); //calculated delay(by trial and error) for the segment to segment movement
	horizontalMT1.stop();
	horizontalMT2.stop();
}


/************ stops the whole cleaner i.e. all motors stops  *******************/
void CleanerDriver::stop() {
	forwardMT1.stop();
	forwardMT2.stop();
	horizontalMT1.stop();
	horizontalMT2.stop();
}

/******** only stops the forward/backward motors****/
void CleanerDriver::for_stop() {
	forwardMT1.stop();
	forwardMT2.stop();
}

/******** only stops the horizontal motors****/
void CleanerDriver::hor_stop() {
	horizontalMT1.stop();
	horizontalMT2.stop();
}

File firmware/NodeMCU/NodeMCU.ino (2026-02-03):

/*************************************************************
  Download latest Blynk library here:
    https://github.com/blynkkk/blynk-library/releases/latest

  Blynk is a platform with iOS and Android apps to control
  Arduino, Raspberry Pi and the likes over the Internet.
  You can easily build graphic interfaces for all your
  projects by simply dragging and dropping widgets.

    Downloads, docs, tutorials: http://www.blynk.cc
    Sketch generator:           http://examples.blynk.cc
    Blynk community:            http://community.blynk.cc
    Follow us:                  http://www.fb.com/blynkapp
                                http://twitter.com/blynk_app

  Blynk library is licensed under MIT license
  This example code is in public domain.

 *************************************************************
  This example runs directly on NodeMCU.

  Note: This requires ESP8266 support package:
    https://github.com/esp8266/Arduino

  Please be sure to select the right NodeMCU module
  in the Tools -> Board menu!

  For advanced settings please follow ESP examples :
   - ESP8266_Standalone_Manual_IP.ino
   - ESP8266_Standalone_SmartConfig.ino
   - ESP8266_Standalone_SSL.ino

  Change WiFi ssid, pass, and Blynk auth token to run :)
  Feel free to apply it to any other example. It's simple!
 *************************************************************/

/* Comment this out to disable prints and save space */
#define BLYNK_PRINT Serial

#include <ESP8266_Lib.h>
#include <BlynkSimpleShieldEsp8266.h>

// Hardware Serial on Mega, Leonardo, Micro...
#define EspSerial Serial1

// Your ESP8266 baud rate:
#define ESP8266_BAUD 9600

// You should get Auth Token in the Blynk App.
// Go to the Project Settings (nut icon).
char auth[] = "YOUR_BLYNK_AUTH_TOKEN";

// Your WiFi credentials. Set password to "" for open networks.
char ssid[] = "YOUR_WIFI_SSID";
char pass[] = "YOUR_WIFI_PASSWORD";

ESP8266 wifi(&EspSerial);


BLYNK_WRITE(V1) {
  TimeInputParam t(param);

  // Process start time

  if (t.hasStartTime())
  {
    Serial.println(String("Start: ") +
                   t.getStartHour() + ":" +
                   t.getStartMinute() + ":" +
                   t.getStartSecond());
  }
  else if (t.isStartSunrise())
  {
    Serial.println("Start at sunrise");
  }
  else if (t.isStartSunset())
  {
    Serial.println("Start at sunset");
  }
  else
  {
    // Do nothing
  }

  // Process stop time

  if (t.hasStopTime())
  {
    Serial.println(String("Stop: ") +
                   t.getStopHour() + ":" +
                   t.getStopMinute() + ":" +
                   t.getStopSecond());
  }
  else if (t.isStopSunrise())
  {
    Serial.println("Stop at sunrise");
  }
  else if (t.isStopSunset())
  {
    Serial.println("Stop at sunset");
  }
  else
  {
    // Do nothing: no stop time was set
  }

  // Process timezone
  // Timezone is already added to start/stop time

  Serial.println(String("Time zone: ") + t.getTZ());

  // Get timezone offset (in seconds)
  Serial.println(String("Time zone offset: ") + t.getTZ_Offset());

  // Process weekdays (1. Mon, 2. Tue, 3. Wed, ...)

  for (int i = 1; i <= 7; i++) {
    if (t.isWeekdaySelected(i)) {
      Serial.println(String("Day ") + i + " is selected");
    }
  }

  Serial.println();
}

BLYNK_WRITE(V2) // Start Button Widget writes to Virtual Pin V2
{
  if(param.asInt() == 1) {     // if Button sends 1
    Serial.println("Cleaner is turned ON");
  }
  else{
    Serial.println("Cleaner is turned OFF");
  }
}


//as soon as connected update TimeInput widget state
BLYNK_CONNECTED() {
  //seconds from the start of a day. 0 - min, 86399 - max
  int startAt = 5 * 60; //00:05

  //seconds from the start of a day. 0 - min, 86399 - max
  int stopAt = (60 + 5) * 60; //01:05

  //timezone
  //full list of supported timezones could be found here
  //https://www.mkyong.com/java/java-display-list-of-timezone-with-gmt/
  char tz[] = "Asia/Karachi";

  Blynk.virtualWrite(V1, startAt, stopAt, tz);

  //you may also pass day
  //char days[] = "1"; //Monday
  //Blynk.virtualWrite(V1, startAt, stopAt, tz, days);

  //or days
  //char days[] = "1,2,3"; //Monday, Tuesday, Wednesday
  //Blynk.virtualWrite(V1, startAt, stopAt, tz, days);
}


void setup()
{
  // Debug console
  Serial.begin(9600);
  //Serial.setDebugOutput(true);
  delay(10);
  // Set ESP8266 baud rate
  EspSerial.begin(ESP8266_BAUD);
  delay(10);
  /*
  WiFi.mode(WIFI_STA);
   int cnt = 0;
  while (WiFi.status() != WL_CONNECTED) {
    delay(500);
    printf("."); // cnt<10 connects to previous wifi network if there is one otherwise cnt>10 enters Smart Config mode
    if (cnt++ >= 10) {
      WiFi.beginSmartConfig();
      Serial.println("Waiting for SmartConfig.");
      while (1) {
        delay(1000);
        printf(".");
        if (WiFi.smartConfigDone()) {
          printf("");
          printf("Smart Config Done.");
          break;
        }
      }
    }
  }*/
  Blynk.begin(auth, wifi, ssid, pass);
  //Blynk.begin(auth, ssid, pass);
  //Blynk.config(auth);
  // You can also specify server:
  //Blynk.begin(auth, ssid, pass, "blynk-cloud.com", 80);
  //Blynk.begin(auth, ssid, pass, IPAddress(192,168,1,100), 8080);
}

void loop()
{
  Blynk.run();
}

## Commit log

2026-02-03 Initial upload: complete project files
    [ATMEGA2560-Schematic.SchDoc, Auto-Solar-Cleaner.PrjPcb, CH340-Sch.SchDoc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]
2026-02-06 Fix link format for PCB pinout image in README
2026-02-06 Update PCB pinout image path in README
2026-02-06 Fix link formatting for PCB board image
2026-02-06 Update PCB image link in README
2026-02-06 Fix image syntax in README for PCB pinout
